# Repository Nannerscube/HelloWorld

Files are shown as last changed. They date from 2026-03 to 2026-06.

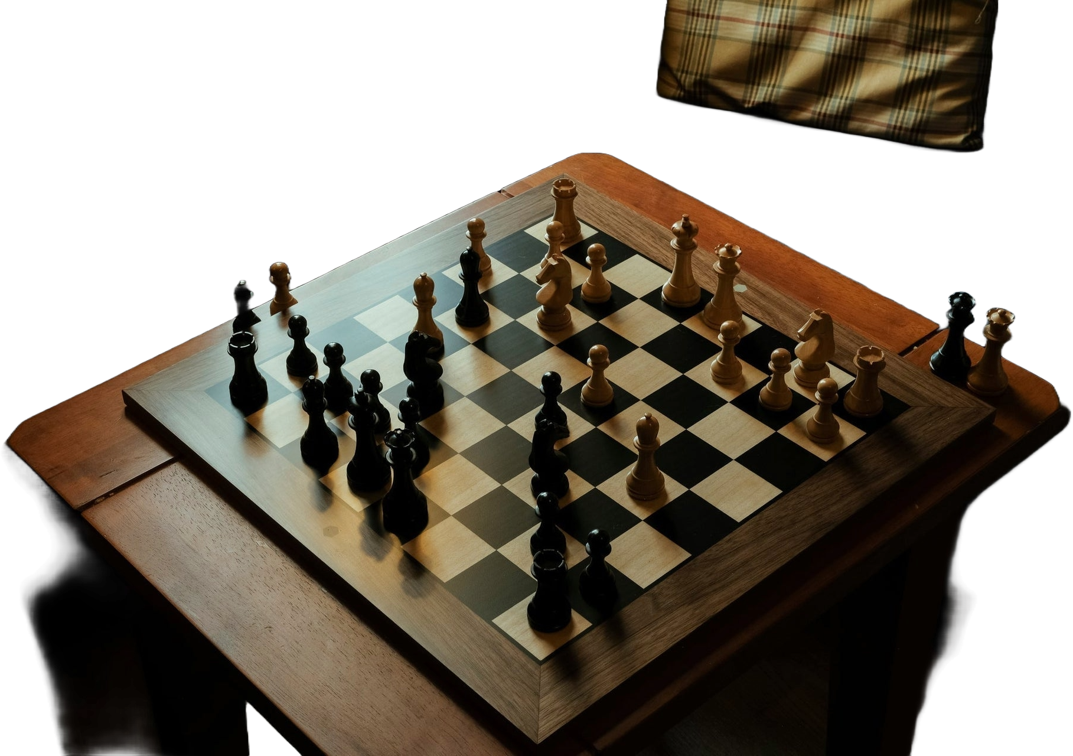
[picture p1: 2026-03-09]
showcase/board_test.jpg

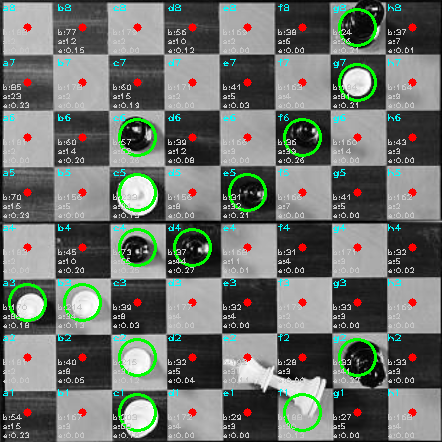
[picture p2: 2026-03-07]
showcase/processed/occupancy_overlay.png

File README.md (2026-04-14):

# Hello World! Chess Bot

A chess-playing robot arm built with Python and C++ (Arduino). It uses computer vision to read the board, Stockfish to calculate the best move, and a 3-axis robot arm to physically execute it — completely autonomously after setup.

## How It Works

The system runs two communication layers:

- **Software layer** — Python handles board state, camera vision (OpenCV), and move generation via Stockfish. Commands like `get_move`, `camera_calibrate`, and `camera_capture_player_move` are exposed to the Arduino via a bridge.
- **Hardware layer** — The Arduino translates logical moves into stepper/servo motor signals, controlling the arm across 3 axes to pick up and place pieces.

**Game loop:**
1. Camera calibrates and captures the initial board state
2. Robot plays as White; player makes a move and presses OK
3. Camera detects the new board state and sends it to Stockfish
4. The arm executes the best move
5. Repeat until checkmate or resignation

## Requirements

### Hardware
| Component | Notes |
|---|---|
| [Arduino UNO Q (2GB/4GB)](https://www.arduino.cc/product-uno-q) | Main controller |
| Arduino CNC Shield + 4× DRV8825 drivers | Motor control |
| 4× NEMA 17 Stepper Motors | Arm movement |
| 1× SG90 Micro Servo | Gripper |
| 3× Endstop Microswitches | Homing |
| Webcam (1080p wide-angle) | Board detection |
| 12V 10A Power Supply | Powers motors |
| 3D-printed arm parts | See [/Arm print](https://github.com/Nannerscube/HelloWorld/tree/main/Arm%20print) |

Total hardware cost: ~€203 + 3D printing

### Software & Libraries

**Arduino:**
- `Arduino_RouterBridge`

**Python (`requirements.txt`):**
```
chess
numpy
opencv-python
```

**External:**
- [Stockfish](https://stockfishchess.org/download/) — place the executable in the AppLabs Python folder, or set the `STOCKFISH_PATH` environment variable

### Optional
- [Visual Studio Code](https://code.visualstudio.com/download)

## Installation

1. Download the ZIP from GitHub and extract the contents onto the Arduino UNO Q
2. Install Python dependencies: `pip install -r requirements.txt`
3. Download Stockfish and place the executable in the AppLabs Python folder

## Configuration

- `ENABLE_PIN = 8`
- Endstops and motor step/dir pins are defined in `sketch.ino`

## Startup Guide

1. Assemble the robot arm — mount motors, gripper, camera, and chessboard in fixed positions
2. Wire Arduino, CNC shield, motors, endstops, button, and servo per the pin mapping; ensure common ground across all components
3. Open AppLabs and create a new project
4. Install the `Arduino_RouterBridge` library and upload `sketch.ino` to the board
5. In the Python environment, ensure `main.py` and `requirements.txt` exist with the required libraries
6. Click **Start** and confirm the bridge reports chess and vision systems are working in the console
7. Power the robot, clear the work area, and press **OK** once — the arm will home itself
8. Press **OK** again to calibrate the camera and verify the board warp
9. Place chess pieces on the board with the robot's side as White
10. Press **OK** again to capture the initial board state — the game begins
11. **Your turn:** make a legal move and press **OK** so the camera captures it
12. **Robot's turn:** wait for the arm to finish and the reference image to refresh before touching the board
13. To stop the game, hold **OK** for ~10 seconds to trigger the resignation flow

## Known Limitations

| Case | Description |
|---|---|
| Uneven lighting | Camera may fail to detect board state correctly |
| Shadows on the board | Can cause false move detections |
| Lighting changes mid-game | Breaks reference frame comparison, causing incorrect detections |
| Castling desync | Engine passes `from_square, to_square` only — rook movement can desync the virtual and physical boards |
| No human promotion support | If the human player reaches promotion, the system has no handler for it |
| No promotion display | Engine promotions are not visually indicated |
| Physical board movement | If the board shifts during play, detection accuracy degrades |

## Project Structure

```
HelloWorld/
├── Arm print/         # 3D print files for the robot arm
├── Python/
│   ├── main.py        # Entry point
│   └── requirements.txt
├── sketch.ino         # Arduino firmware
└── tests/
    ├── grippertest.ino
    └── ...
```

## Acknowledgements

- [Stockfish](https://stockfishchess.org/) — chess engine
- [python-chess](https://python-chess.readthedocs.io/) — board logic
- [OpenCV](https://opencv.org/) — computer vision

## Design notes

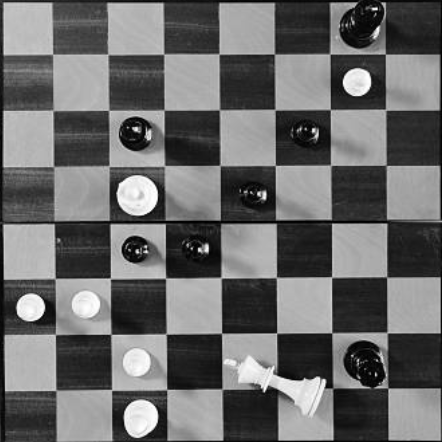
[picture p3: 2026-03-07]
showcase/processed/warped_board.png

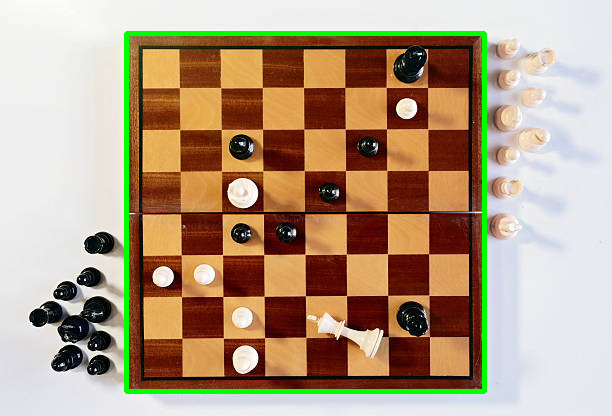
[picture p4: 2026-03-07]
showcase/processed/recognized_board.png

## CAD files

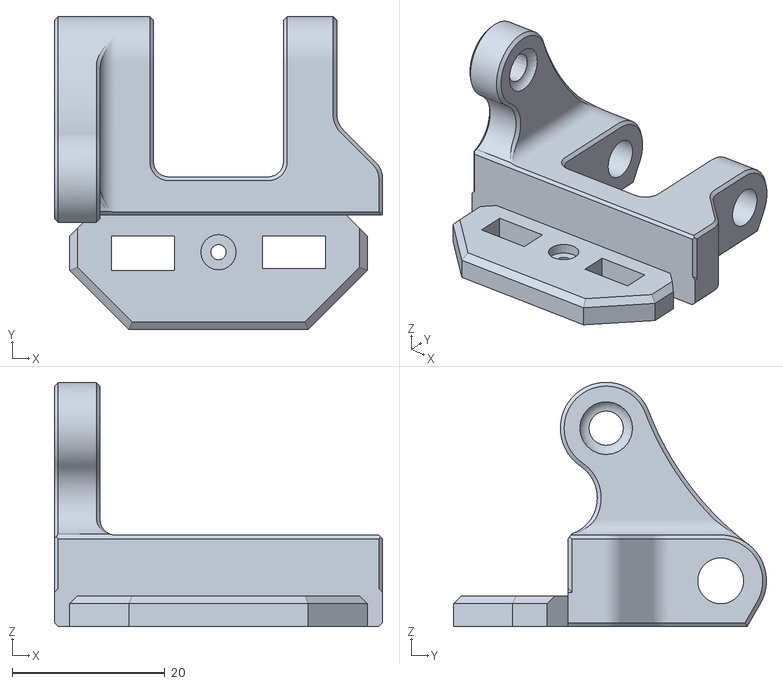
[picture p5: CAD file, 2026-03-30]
Arm print/manipulator.stl
43.0 x 41.0 x 32.0

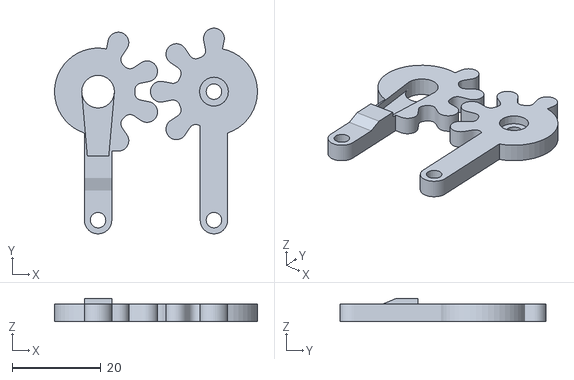
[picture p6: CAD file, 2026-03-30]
Arm print/gears.stl
45.8 x 46.4 x 5.20

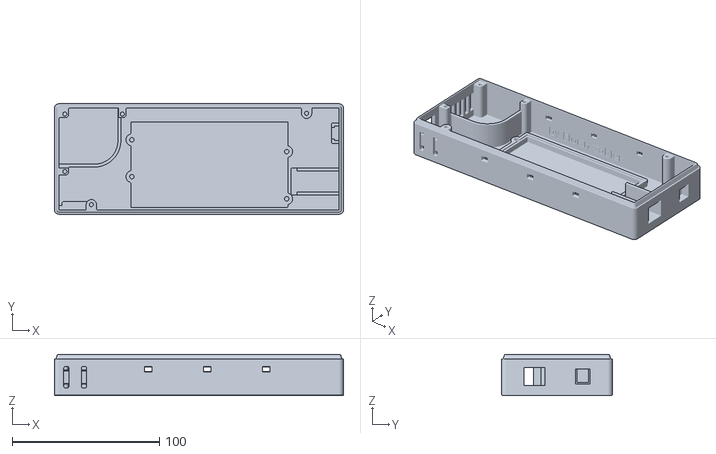
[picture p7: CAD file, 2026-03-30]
Arm print/control_bottom.stl
196.0 x 75.0 x 28.0

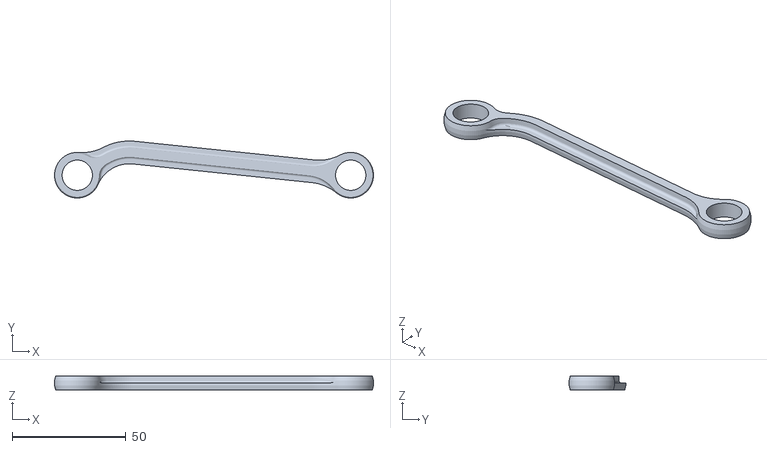
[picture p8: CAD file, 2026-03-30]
Arm print/pleuel_bend.stl
140.0 x 25.0 x 6.00

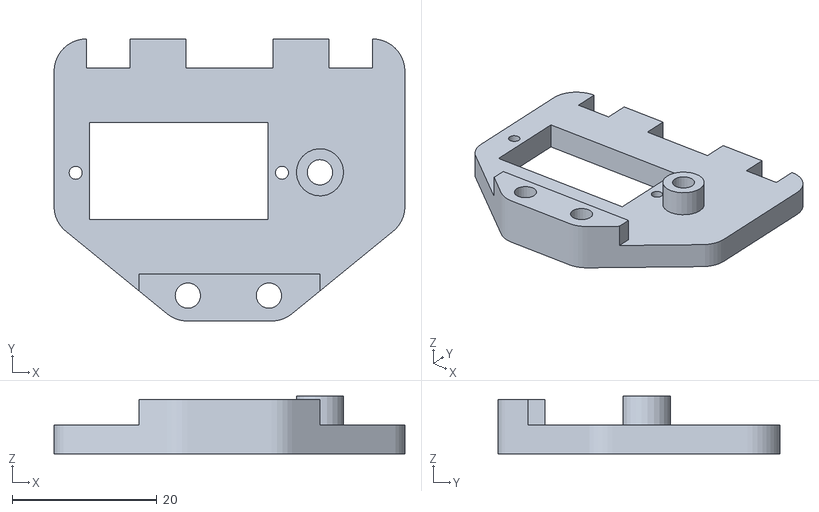
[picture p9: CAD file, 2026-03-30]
Arm print/servo-plate.stl
48.5 x 39.0 x 8.00

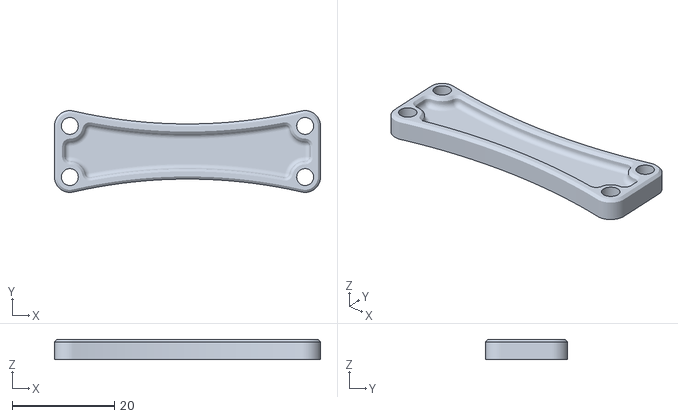
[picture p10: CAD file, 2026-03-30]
Arm print/stabilizer.stl
52.0 x 16.0 x 4.00

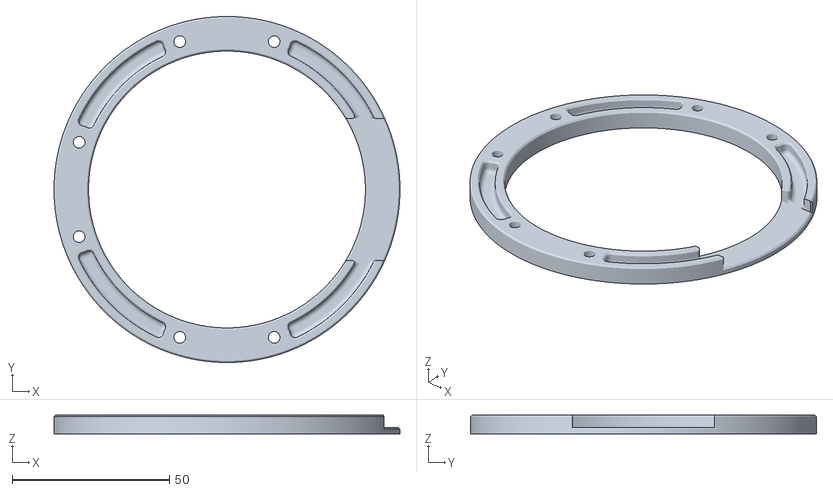
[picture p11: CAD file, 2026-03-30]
Arm print/baseRing.stl
110.0 x 110.0 x 6.00

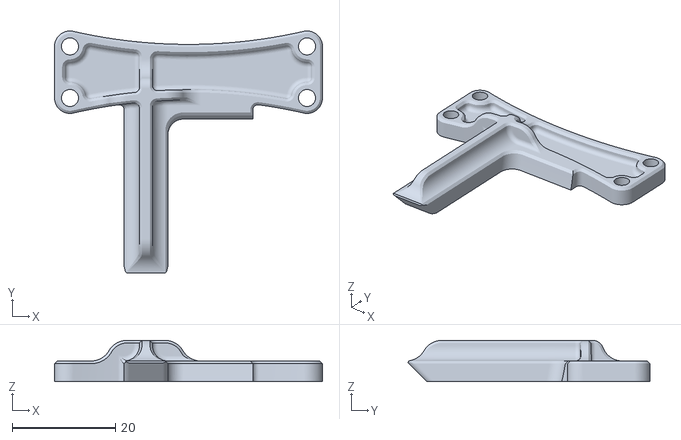
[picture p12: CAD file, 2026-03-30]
Arm print/stabilizer_endstop.stl
52.0 x 47.0 x 8.00

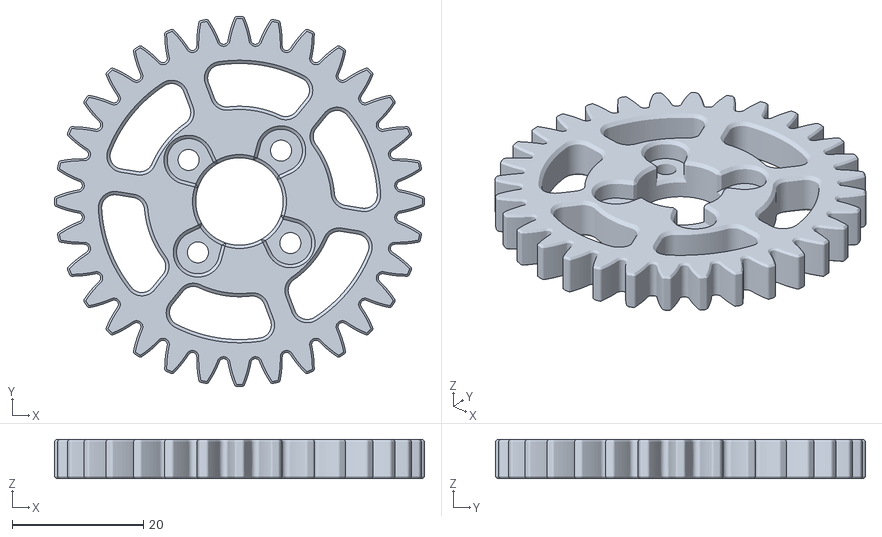
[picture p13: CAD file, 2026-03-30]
Arm print/GearBig_0.05mmTolerance.stl
56.3 x 56.3 x 6.00

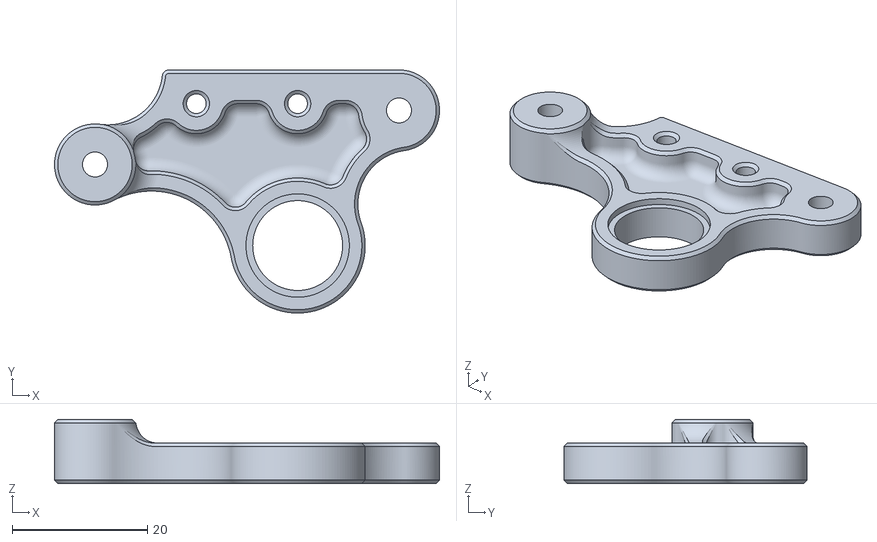
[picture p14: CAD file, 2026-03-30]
Arm print/triplate.stl
57.0 x 36.0 x 9.50

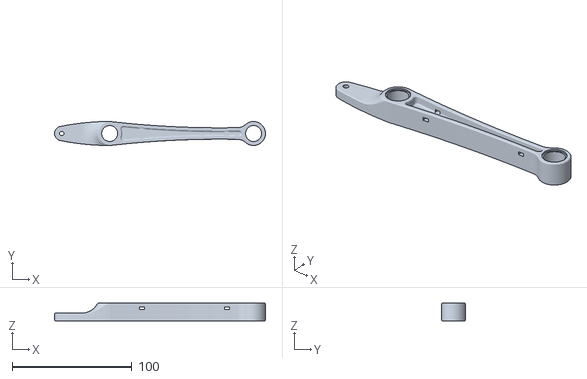
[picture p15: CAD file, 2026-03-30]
Arm print/upperShank.stl
176.0 x 20.0 x 15.0

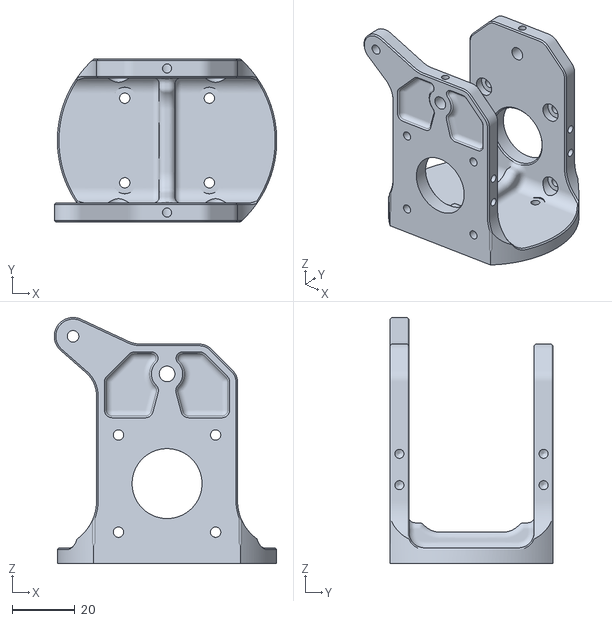
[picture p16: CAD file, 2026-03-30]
Arm print/base.stl
71.0 x 52.0 x 78.5

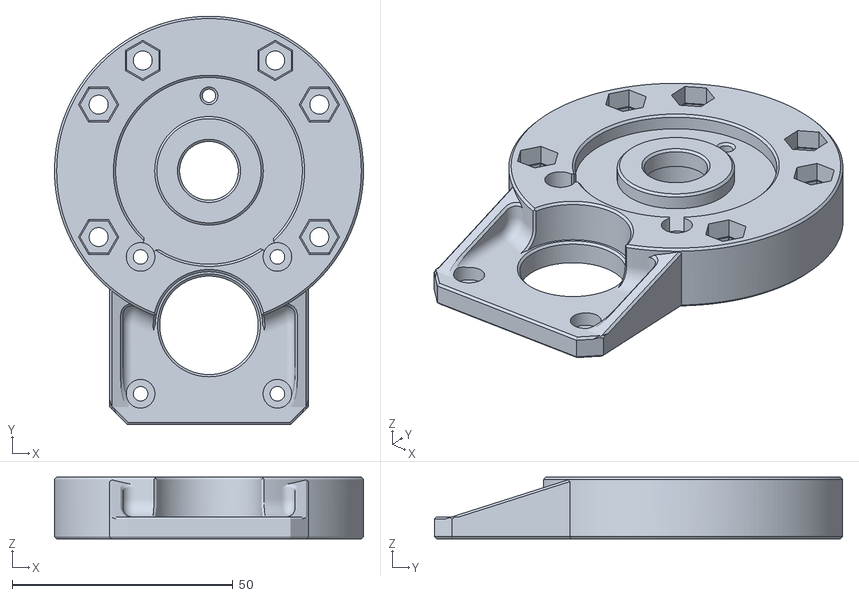
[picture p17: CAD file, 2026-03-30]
Arm print/socket.stl
70.0 x 92.5 x 14.0

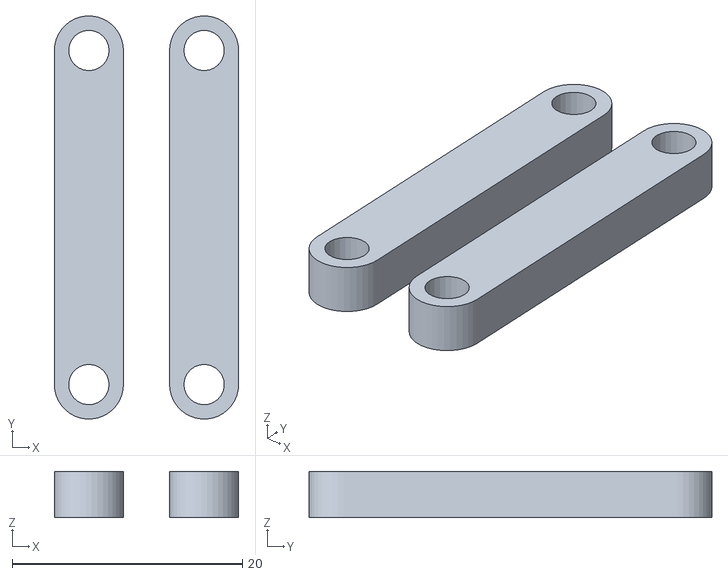
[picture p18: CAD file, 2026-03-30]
Arm print/parallel-bar.stl
16.0 x 35.0 x 4.00

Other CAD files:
Arm print/lever.stl
Arm print/pleuel.stl
Arm print/GearSmall(gold) modified.stl
Arm print/GearSmall.stl
Arm print/GearRotate_0.05mmTolerance.stl
Arm print/grip-part.stl
Arm print/lowerShank.stl

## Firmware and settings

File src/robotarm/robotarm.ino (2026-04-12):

// ██╗  ██╗███████╗██╗     ██╗      ██████╗   ██╗    ██╗ ██████╗ ██████╗ ██╗     ██████╗
// ██║  ██║██╔════╝██║     ██║     ██╔═══██╗  ██║    ██║██╔═══██╗██╔══██╗██║     ██╔══██╗
// ███████║█████╗  ██║     ██║     ██║   ██║  ██║ █╗ ██║██║   ██║██████╔╝██║     ██║  ██║
// ██╔══██║██╔══╝  ██║     ██║     ██║   ██║  ██║███╗██║██║   ██║██╔══██╗██║     ██║  ██║
// ██║  ██║███████╗███████╗███████╗╚██████╔╝  ╚███╔███╔╝╚██████╔╝██║  ██║███████╗██████╔╝
// ╚═╝  ╚═╝╚══════╝╚══════╝╚══════╝ ╚═════╝    ╚══╝╚══╝  ╚═════╝ ╚═╝  ╚═╝╚══════╝╚═════╝

// ██████╗  ██████╗ ██████╗  ██████╗ ████████╗     █████╗ ██████╗ ███╗   ███╗
// ██╔══██╗██╔═══██╗██╔══██╗██╔═══██╗╚══██╔══╝    ██╔══██╗██╔══██╗████╗ ████║
// ██████╔╝██║   ██║██████╔╝██║   ██║   ██║       ███████║██████╔╝██╔████╔██║
// ██╔══██╗██║   ██║██╔══██╗██║   ██║   ██║       ██╔══██║██╔══██╗██║╚██╔╝██║
// ██║  ██║╚██████╔╝██████╔╝╚██████╔╝   ██║       ██║  ██║██║  ██║██║ ╚═╝ ██║
// ╚═╝  ╚═╝ ╚═════╝ ╚═════╝  ╚═════╝    ╚═╝       ╚═╝  ╚═╝╚═╝  ╚═╝╚═╝     ╚═╝
// This file needs to read input from chess notation and make the robot arm make that 

#include <Arduino_RouterBridge.h>


// ██████╗ ██╗███╗   ██╗ ██████╗ ██╗   ██╗████████╗
// ██╔══██╗██║████╗  ██║██╔═══██╗██║   ██║╚══██╔══╝
// ██████╔╝██║██╔██╗ ██║██║   ██║██║   ██║   ██║   
// ██╔═══╝ ██║██║╚██╗██║██║   ██║██║   ██║   ██║   
// ██║     ██║██║ ╚████║╚██████╔╝╚██████╔╝   ██║   
// ╚═╝     ╚═╝╚═╝  ╚═══╝ ╚═════╝  ╚═════╝    ╚═╝   

#define ENABLE_PIN 8

#define X_DIR  5
#define X_STEP 2

#define Y_DIR  6
#define Y_STEP 3

#define Z_DIR  7
#define Z_STEP 4
#define Z_ENDSTOP 11

#define SERVO_PIN 12


//  ██████╗ ██████╗ ███╗   ██╗███████╗████████╗ █████╗ ███╗   ██╗████████╗███████╗
// ██╔════╝██╔═══██╗████╗  ██║██╔════╝╚══██╔══╝██╔══██╗████╗  ██║╚══██╔══╝██╔════╝
// ██║     ██║   ██║██╔██╗ ██║███████╗   ██║   ███████║██╔██╗ ██║   ██║   ███████╗
// ██║     ██║   ██║██║╚██╗██║╚════██║   ██║   ██╔══██║██║╚██╗██║   ██║   ╚════██║
// ╚██████╗╚██████╔╝██║ ╚████║███████║   ██║   ██║  ██║██║ ╚████║   ██║   ███████║
//  ╚═════╝ ╚═════╝ ╚═╝  ╚═══╝╚══════╝   ╚═╝   ╚═╝  ╚═╝╚═╝  ╚═══╝   ╚═╝   ╚══════╝

#define STEPS_PER_REV 50
#define MICROSTEP     1
#define STEP_DELAY_US 6000
#define Y_STEP_DELAY_MS 3000
#define Z_STEP_DELAY_MS 8000  // slower than Y
#define Z_EXTRA_STEPS 100     // extra Z after Y stops

#define X_ROTATE_STEPS 168    // steps for 90 degrees more less

#define GRIPPER_CLOSED 2200
#define GRIPPER_OPEN   1000

#define MAX_MOVES 30

struct Move {
  int  dirPin1, stepPin1;
  bool dir1;
  int  dirPin2, stepPin2;
  bool dir2;
  int  steps;
  bool isTwoMotors;

  Move() {}
  Move(int dp1, int sp1, bool d1, int dp2, int sp2, bool d2, int s, bool two)
    : dirPin1(dp1), stepPin1(sp1), dir1(d1),
      dirPin2(dp2), stepPin2(sp2), dir2(d2),
      steps(s), isTwoMotors(two) {}
};
Move moveQueue[MAX_MOVES];
int  moveCount = 0;

void rememberMove(int dirPin1, int stepPin1, int steps, bool clockwise);
void rememberMove(int dirPin1, int stepPin1, bool dir1,
                  int dirPin2, int stepPin2, bool dir2,
                  int steps);
void goHome();


// ███████╗███████╗████████╗██╗   ██╗██████╗ 
// ██╔════╝██╔════╝╚══██╔══╝██║   ██║██╔══██╗
// ███████╗█████╗     ██║   ██║   ██║██████╔╝
// ╚════██║██╔══╝     ██║   ██║   ██║██╔═══╝ 
// ███████║███████╗   ██║   ╚██████╔╝██║     
// ╚══════╝╚══════╝   ╚═╝    ╚═════╝ ╚═╝     

void setup() {
  Monitor.begin();

  pinMode(X_DIR, OUTPUT);
  pinMode(X_STEP, OUTPUT);
  pinMode(Y_DIR, OUTPUT);
  pinMode(Y_STEP, OUTPUT);
  pinMode(Z_DIR, OUTPUT);
  pinMode(Z_STEP, OUTPUT);
  pinMode(ENABLE_PIN, OUTPUT);
  pinMode(Z_ENDSTOP, INPUT_PULLUP);

  digitalWrite(ENABLE_PIN, LOW);

  // Go to initial position
  delay(2000);
  initializePosition();
  Monitor.println("Finished YZ Home");
  rotateX90(false);
  Monitor.println("Finished X 90 Rotation");
  delay(500);
}


// ██╗      ██████╗  ██████╗ ██████╗ 
// ██║     ██╔═══██╗██╔═══██╗██╔══██╗
// ██║     ██║   ██║██║   ██║██████╔╝
// ██║     ██║   ██║██║   ██║██╔═══╝ 
// ███████╗╚██████╔╝╚██████╔╝██║     
// ╚══════╝ ╚═════╝  ╚═════╝ ╚═╝     

void loop() {
  setGripper(GRIPPER_OPEN);
  goToSquare('h', 8);
  while(true);
}


// ██╗      ██████╗  ██████╗ ██╗ ██████╗
// ██║     ██╔═══██╗██╔════╝ ██║██╔════╝
// ██║     ██║   ██║██║  ███╗██║██║     
// ██║     ██║   ██║██║   ██║██║██║     
// ███████╗╚██████╔╝╚██████╔╝██║╚██████╗
// ╚══════╝ ╚═════╝  ╚═════╝ ╚═╝ ╚═════╝
// Takes a square in chess notation (e.g. "A1", "H8") and moves the arm to it
void goToSquare(char col, int row) {
  moveCount = 0;
  rotateX90(true);
  switch (col) {
    case 'A': case 'a':
      switch (row) {
        case 1: goToA1(); break;
        case 2: goToA2(); break;
        case 3: goToA3(); break;
        case 4: goToA4(); break;
        case 5: goToA5(); break;
        case 6: goToA6(); break;
        case 7: goToA7(); break;
        case 8: goToA8(); break;
      } break;

    case 'B': case 'b':
      switch (row) {
        case 1: goToB1(); break;
        case 2: goToB2(); break;
        case 3: goToB3(); break;
        case 4: goToB4(); break;
        case 5: goToB5(); break;
        case 6: goToB6(); break;
        case 7: goToB7(); break;
        case 8: goToB8(); break;
      } break;

    case 'C': case 'c':
      switch (row) {
        case 1: goToC1(); break;
        case 2: goToC2(); break;
        case 3: goToC3(); break;
        case 4: goToC4(); break;
        case 5: goToC5(); break;
        case 6: goToC6(); break;
        case 7: goToC7(); break;
        case 8: goToC8(); break;
      } break;

    case 'D': case 'd':
      switch (row) {
        case 1: goToD1(); break;
        case 2: goToD2(); break;
        case 3: goToD3(); break;
        case 4: goToD4(); break;
        case 5: goToD5(); break;
        case 6: goToD6(); break;
        case 7: goToD7(); break;
        case 8: goToD8(); break;
      } break;

    case 'E': case 'e':
      switch (row) {
        case 1: goToE1(); break;
        case 2: goToE2(); break;
        case 3: goToE3(); break;
        case 4: goToE4(); break;
        case 5: goToE5(); break;
        case 6: goToE6(); break;
        case 7: goToE7(); break;
        case 8: goToE8(); break;
      } break;

    case 'F': case 'f':
      switch (row) {
        case 1: goToF1(); break;
        case 2: goToF2(); break;
        case 3: goToF3(); break;
        case 4: goToF4(); break;
        case 5: goToF5(); break;
        case 6: goToF6(); break;
        case 7: goToF7(); break;
        case 8: goToF8(); break;
      } break;

    case 'G': case 'g':
      switch (row) {
        case 1: goToG1(); break;
        case 2: goToG2(); break;
        case 3: goToG3(); break;
        case 4: goToG4(); break;
        case 5: goToG5(); break;
        case 6: goToG6(); break;
        case 7: goToG7(); break;
        case 8: goToG8(); break;
      } break;

    case 'H': case 'h':
      switch (row) {
        case 1: goToH1(); break;
        case 2: goToH2(); break;
        case 3: goToH3(); break;
        case 4: goToH4(); break;
        case 5: goToH5(); break;
        case 6: goToH6(); break;
        case 7: goToH7(); break;
        case 8: goToH8(); break;
      } break;
  }
}


// ██████╗ ███████╗ ██████╗ ██████╗ ██████╗ ██████╗ ██╗███╗   ██╗ ██████╗ 
// ██╔══██╗██╔════╝██╔════╝██╔═══██╗██╔══██╗██╔══██╗██║████╗  ██║██╔════╝ 
// ██████╔╝█████╗  ██║     ██║   ██║██████╔╝██║  ██║██║██╔██╗ ██║██║  ███╗
// ██╔══██╗██╔══╝  ██║     ██║   ██║██╔══██╗██║  ██║██║██║╚██╗██║██║   ██║
// ██║  ██║███████╗╚██████╗╚██████╔╝██║  ██║██████╔╝██║██║ ╚████║╚██████╔╝
// ╚═╝  ╚═╝╚══════╝ ╚═════╝ ╚═════╝ ╚═╝  ╚═╝╚═════╝ ╚═╝╚═╝  ╚═══╝ ╚═════╝ 

void rememberMove(int dirPin1, int stepPin1, int steps, bool clockwise) {
  if (moveCount >= MAX_MOVES) return;
  moveQueue[moveCount++] = Move(dirPin1, stepPin1, clockwise, 0, 0, false, steps, false);
}

void rememberMove(int dirPin1, int stepPin1, bool dir1,
                  int dirPin2, int stepPin2, bool dir2,
                  int steps) {
  if (moveCount >= MAX_MOVES) return;
  moveQueue[moveCount++] = Move(dirPin1, stepPin1, dir1, dirPin2, stepPin2, dir2, steps, true);
}

void goHome() {
  for (int i = moveCount - 1; i >= 0; i--) {
    Move& m = moveQueue[i];
    if (m.isTwoMotors) {
      stepTwoMotors(m.dirPin1, m.stepPin1, !m.dir1,
                    m.dirPin2, m.stepPin2, !m.dir2,
                    m.steps);
    } else {
      stepMotor(m.dirPin1, m.stepPin1, m.steps, !m.dir1);
    }
  }
  moveCount = 0;
  rotateX90(false);
  delay(300);
}


// ███╗   ███╗ ██████╗ ████████╗ ██████╗ ██████╗ ███████╗
// ████╗ ████║██╔═══██╗╚══██╔══╝██╔═══██╗██╔══██╗██╔════╝
// ██╔████╔██║██║   ██║   ██║   ██║   ██║██████╔╝███████╗
// ██║╚██╔╝██║██║   ██║   ██║   ██║   ██║██╔══██╗╚════██║
// ██║ ╚═╝ ██║╚██████╔╝   ██║   ╚██████╔╝██║  ██║███████║
// ╚═╝     ╚═╝ ╚═════╝    ╚═╝    ╚═════╝ ╚═╝  ╚═╝╚══════╝

void setGripper(unsigned int pulse) {
  for (unsigned char i = 0; i < 8; i++) {
    digitalWrite(SERVO_PIN, HIGH);
    delayMicroseconds(pulse);
    digitalWrite(SERVO_PIN, LOW);
  }
}

void stepMotor(int dirPin, int stepPin, int steps, bool clockwise) {
  digitalWrite(dirPin, clockwise ? HIGH : LOW);
  delay(1);
  for (int i = 0; i < steps * MICROSTEP; i++) {
    digitalWrite(stepPin, HIGH);
    delayMicroseconds(STEP_DELAY_US);
    digitalWrite(stepPin, LOW);
    delayMicroseconds(STEP_DELAY_US);
  }
}

void stepTwoMotors(int dirPin1, int stepPin1, bool dir1,
                   int dirPin2, int stepPin2, bool dir2,
                   int steps) {
  digitalWrite(dirPin1, dir1 ? HIGH : LOW);
  digitalWrite(dirPin2, dir2 ? HIGH : LOW);
  delay(1);
  for (int i = 0; i < steps * MICROSTEP; i++) {
    digitalWrite(stepPin1, HIGH);
    digitalWrite(stepPin2, HIGH);
    delayMicroseconds(STEP_DELAY_US);
    digitalWrite(stepPin1, LOW);
    digitalWrite(stepPin2, LOW);
    delayMicroseconds(STEP_DELAY_US);
  }
}


// ██████╗  ██████╗ ███████╗██╗████████╗██╗ ██████╗ ███╗   ██╗███████╗
// ██╔══██╗██╔═══██╗██╔════╝██║╚══██╔══╝██║██╔═══██╗████╗  ██║██╔════╝
// ██████╔╝██║   ██║███████╗██║   ██║   ██║██║   ██║██╔██╗ ██║███████╗
// ██╔═══╝ ██║   ██║╚════██║██║   ██║   ██║██║   ██║██║╚██╗██║╚════██║
// ██║     ╚██████╔╝███████║██║   ██║   ██║╚██████╔╝██║ ╚████║███████║
// ╚═╝      ╚═════╝ ╚══════╝╚═╝   ╚═╝   ╚═╝ ╚═════╝ ╚═╝  ╚═══╝╚══════╝

void initializePosition() {
  digitalWrite(Y_DIR, LOW);  // Y backward
  digitalWrite(Z_DIR, HIGH); // Z up

  int zCounter = 0;

  while (digitalRead(Z_ENDSTOP) == LOW) {
    digitalWrite(Y_STEP, HIGH);
    delayMicroseconds(Y_STEP_DELAY_MS);
    digitalWrite(Y_STEP, LOW);
    delayMicroseconds(Y_STEP_DELAY_MS);

    zCounter++;
    if (zCounter >= 3) {
      digitalWrite(Z_STEP, HIGH);
      delayMicroseconds(Z_STEP_DELAY_MS);
      digitalWrite(Z_STEP, LOW);
      delayMicroseconds(Z_STEP_DELAY_MS);
      zCounter = 0;
    }
  }

  // Small back off on Y
  digitalWrite(Y_DIR, HIGH);
  for (int i = 0; i < 20; i++) {
    digitalWrite(Y_STEP, HIGH);
    delayMicroseconds(Y_STEP_DELAY_MS);
    digitalWrite(Y_STEP, LOW);
    delayMicroseconds(Y_STEP_DELAY_MS);
  }

  // Moving Z further up
  for (int i = 0; i < Z_EXTRA_STEPS; i++) {
    digitalWrite(Z_STEP, HIGH);
    delayMicroseconds(Z_STEP_DELAY_MS);
    digitalWrite(Z_STEP, LOW);
    delayMicroseconds(Z_STEP_DELAY_MS);
  }
}

void rotateX90(bool clockwise) {
  digitalWrite(X_DIR, clockwise ? HIGH : LOW);
  delay(1);
  for (int i = 0; i < X_ROTATE_STEPS; i++) {
    digitalWrite(X_STEP, HIGH);
    delayMicroseconds(10000);
    digitalWrite(X_STEP, LOW);
    delayMicroseconds(10000);
  }
}


void goToA1() {
  rememberMove(Y_DIR, Y_STEP, STEPS_PER_REV, false);
  stepMotor(Y_DIR, Y_STEP, STEPS_PER_REV, false);
  delay(500);
  rememberMove(Z_DIR, Z_STEP, STEPS_PER_REV, false);
  stepMotor(Z_DIR, Z_STEP, STEPS_PER_REV, false);
  delay(500);
  rememberMove(X_DIR, X_STEP, 120, true);
  stepMotor(X_DIR, X_STEP, 120, true);
  delay(500);
  rememberMove(Z_DIR, Z_STEP, 20, true);
  stepMotor(Z_DIR, Z_STEP, 20, true);
  delay(500);
  rememberMove(Z_DIR, Z_STEP, false,
                Y_DIR, Y_STEP, true,
                90);
  stepTwoMotors(Z_DIR, Z_STEP, false,
                Y_DIR, Y_STEP, true,
                90);
  delay(500);
  rememberMove(Z_DIR, Z_STEP, 8, false);
  stepMotor(Z_DIR, Z_STEP, 8, false);
  delay(500);
  rememberMove(Z_DIR, Z_STEP, false,
                Y_DIR, Y_STEP, true,
                30);
  stepTwoMotors(Z_DIR, Z_STEP, false,
                Y_DIR, Y_STEP, true,
                30);
  delay(500);
  setGripper(GRIPPER_CLOSED);
  goHome();
}
void goToA2() {
  rememberMove(Y_DIR, Y_STEP, STEPS_PER_REV, false);
  stepMotor(Y_DIR, Y_STEP, STEPS_PER_REV, false);
  delay(500);
  rememberMove(Z_DIR, Z_STEP, STEPS_PER_REV, false);
  stepMotor(Z_DIR, Z_STEP, STEPS_PER_REV, false);
  delay(500);
  rememberMove(X_DIR, X_STEP, 104  , true);
  stepMotor(X_DIR, X_STEP, 104, true);
  delay(500);
  rememberMove(Z_DIR, Z_STEP, 35, true);
  stepMotor(Z_DIR, Z_STEP, 35, true);
  delay(500);
  rememberMove(Z_DIR, Z_STEP, false,
                Y_DIR, Y_STEP, true,
                107);
  stepTwoMotors(Z_DIR, Z_STEP, false,
                Y_DIR, Y_STEP, true,
                107);
  delay(500);
  rememberMove(Z_DIR, Z_STEP, 8, false);
  stepMotor(Z_DIR, Z_STEP, 8, false);
  delay(500);
  rememberMove(Z_DIR, Z_STEP, false,
                Y_DIR, Y_STEP, true,
                10);
  stepTwoMotors(Z_DIR, Z_STEP, false,
                Y_DIR, Y_STEP, true,
                10);
  delay(500);
  setGripper(GRIPPER_CLOSED);
  goHome();
}
void goToA3() {
  rememberMove(Y_DIR, Y_STEP, STEPS_PER_REV, false);
  stepMotor(Y_DIR, Y_STEP, STEPS_PER_REV, false);
  delay(500);
  rememberMove(Z_DIR, Z_STEP, STEPS_PER_REV, false);
  stepMotor(Z_DIR, Z_STEP, STEPS_PER_REV, false);
  delay(500);
  rememberMove(X_DIR, X_STEP, 91, true);
  stepMotor(X_DIR, X_STEP, 91, true);
  delay(500);
  rememberMove(Z_DIR, Z_STEP, 55, true);
  stepMotor(Z_DIR, Z_STEP, 55, true);
  delay(500);
  rememberMove(Z_DIR, Z_STEP, false,
                Y_DIR, Y_STEP, true,
                107);
  stepTwoMotors(Z_DIR, Z_STEP, false,
                Y_DIR, Y_STEP, true,
                107);
  delay(500);
  rememberMove(Z_DIR, Z_STEP, 8, false);
  stepMotor(Z_DIR, Z_STEP, 8, false);
  delay(500);
  rememberMove(Z_DIR, Z_STEP, false,
                Y_DIR, Y_STEP, true,
                20);
  stepTwoMotors(Z_DIR, Z_STEP, false,
                Y_DIR, Y_STEP, true,
                20);
  delay(500);
  setGripper(GRIPPER_CLOSED);
  goHome();
}
void goToA4() {
  rememberMove(Y_DIR, Y_STEP, STEPS_PER_REV, false);
  stepMotor(Y_DIR, Y_STEP, STEPS_PER_REV, false);
  delay(500);
  rememberMove(Z_DIR, Z_STEP, STEPS_PER_REV, false);
  stepMotor(Z_DIR, Z_STEP, STEPS_PER_REV, false);
  delay(500);
  rememberMove(X_DIR, X_STEP, 79, true);
  stepMotor(X_DIR, X_STEP, 79, true);
  delay(500);
  rememberMove(Z_DIR, Z_STEP, 75, true);
  stepMotor(Z_DIR, Z_STEP, 75, true);
  delay(500);
  rememberMove(Z_DIR, Z_STEP, false,
                Y_DIR, Y_STEP, true,
                115);
  stepTwoMotors(Z_DIR, Z_STEP, false,
                Y_DIR, Y_STEP, true,
                115);
  delay(500);
  rememberMove(Z_DIR, Z_STEP, 10, false);
  stepMotor(Z_DIR, Z_STEP, 10, false);
  delay(500);
  rememberMove(Z_DIR, Z_STEP, false,
                Y_DIR, Y_STEP, true,
                30);
  stepTwoMotors(Z_DIR, Z_STEP, false,
                Y_DIR, Y_STEP, true,
                30);
  delay(500);
  setGripper(GRIPPER_CLOSED);
  goHome();
}
void goToA5() {
  rememberMove(Y_DIR, Y_STEP, STEPS_PER_REV, false);
  stepMotor(Y_DIR, Y_STEP, STEPS_PER_REV, false);
  delay(500);
  rememberMove(Z_DIR, Z_STEP, STEPS_PER_REV, false);
  stepMotor(Z_DIR, Z_STEP, STEPS_PER_REV, false);
  delay(500);
  rememberMove(X_DIR, X_STEP, 71, true);
  stepMotor(X_DIR, X_STEP, 71, true);
  delay(500);
  rememberMove(Z_DIR, Z_STEP, 70, true);
  stepMotor(Z_DIR, Z_STEP, 70, true);
  delay(500);
  rememberMove(Z_DIR, Z_STEP, false,
                Y_DIR, Y_STEP, true,
                125);
  stepTwoMotors(Z_DIR, Z_STEP, false,
                Y_DIR, Y_STEP, true,
                125);
  delay(500);
  rememberMove(Z_DIR, Z_STEP, 40, true);
  stepMotor(Z_DIR, Z_STEP, 40, true);
  delay(500);
  rememberMove(Z_DIR, Z_STEP, 8, false);
  stepMotor(Z_DIR, Z_STEP, 8, false);
  delay(500);
  rememberMove(Z_DIR, Z_STEP, false,
                Y_DIR, Y_STEP, true,
                30);
  stepTwoMotors(Z_DIR, Z_STEP, false,
                Y_DIR, Y_STEP, true,
                30);
  delay(500);
  setGripper(GRIPPER_CLOSED);
  goHome();
}
void goToA6() {
    rememberMove(Y_DIR, Y_STEP, STEPS_PER_REV, false);
  stepMotor(Y_DIR, Y_STEP, STEPS_PER_REV, false);
  delay(500);
  rememberMove(Z_DIR, Z_STEP, STEPS_PER_REV, false);
  stepMotor(Z_DIR, Z_STEP, STEPS_PER_REV, false);
  delay(500);
  rememberMove(X_DIR, X_STEP, 70, true);
  stepMotor(X_DIR, X_STEP, 70, true);
  delay(500);
  rememberMove(Z_DIR, Z_STEP, 70, true);
  stepMotor(Z_DIR, Z_STEP, 70, true);
  delay(500);
  rememberMove(Z_DIR, Z_STEP, false,
                Y_DIR, Y_STEP, true,
                125);
  stepTwoMotors(Z_DIR, Z_STEP, false,
                Y_DIR, Y_STEP, true,
                125);
  delay(500);
  rememberMove(Z_DIR, Z_STEP, 60, true);
  stepMotor(Z_DIR, Z_STEP, 60, true);
  delay(500);
  rememberMove(Z_DIR, Z_STEP, false,
                Y_DIR, Y_STEP, true,
                40);
  stepTwoMotors(Z_DIR, Z_STEP, false,
                Y_DIR, Y_STEP, true,
                40);
  delay(500);
  setGripper(GRIPPER_CLOSED);
  goHome();
}
void goToA7() {
  rememberMove(Y_DIR, Y_STEP, STEPS_PER_REV, false);
  stepMotor(Y_DIR, Y_STEP, STEPS_PER_REV, false);
  delay(500);
  rememberMove(Z_DIR, Z_STEP, STEPS_PER_REV, false);
  stepMotor(Z_DIR, Z_STEP, STEPS_PER_REV, false);
  delay(500);
  rememberMove(X_DIR, X_STEP, 65, true);
  stepMotor(X_DIR, X_STEP, 65, true);
  delay(500);
  rememberMove(Z_DIR, Z_STEP, 70, true);
  stepMotor(Z_DIR, Z_STEP, 70, true);
  delay(500);
  rememberMove(Z_DIR, Z_STEP, false,
                Y_DIR, Y_STEP, true,
                125);
  stepTwoMotors(Z_DIR, Z_STEP, false,
                Y_DIR, Y_STEP, true,
                125);
  delay(500);
  rememberMove(Z_DIR, Z_STEP, 95, true);
  stepMotor(Z_DIR, Z_STEP, 95, true);
  delay(500);
  rememberMove(Z_DIR, Z_STEP, false,
                Y_DIR, Y_STEP, true,
                55);
  stepTwoMotors(Z_DIR, Z_STEP, false,
                Y_DIR, Y_STEP, true,
                55);
  delay(500);
  setGripper(GRIPPER_CLOSED);
  goHome();
}
void goToA8() {
  rememberMove(Y_DIR, Y_STEP, STEPS_PER_REV, false);
  stepMotor(Y_DIR, Y_STEP, STEPS_PER_REV, false);
  delay(500);
  rememberMove(Z_DIR, Z_STEP, STEPS_PER_REV, false);
  stepMotor(Z_DIR, Z_STEP, STEPS_PER_REV, false);
  delay(500);
  rememberMove(X_DIR, X_STEP, 58, true);
  stepMotor(X_DIR, X_STEP, 58, true);
  delay(500);
  rememberMove(Z_DIR, Z_STEP, 70, true);
  stepMotor(Z_DIR, Z_STEP, 70, true);
  delay(500);
  rememberMove(Z_DIR, Z_STEP, false,
                Y_DIR, Y_STEP, true,
                125);
  stepTwoMotors(Z_DIR, Z_STEP, false,
                Y_DIR, Y_STEP, true,
                125);
  delay(500);
  rememberMove(Z_DIR, Z_STEP, 70, true);
  stepMotor(Z_DIR, Z_STEP, 70, true);
  delay(500);
  rememberMove(Z_DIR, Z_STEP, false,
                Y_DIR, Y_STEP, true,
                33);
  stepTwoMotors(Z_DIR, Z_STEP, false,
                Y_DIR, Y_STEP, true,
                33);
  delay(500);
  rememberMove(Z_DIR, Z_STEP, 70, true);
  stepMotor(Z_DIR, Z_STEP, 70, true);
  delay(500);
  rememberMove(Z_DIR, Z_STEP, false,
                Y_DIR, Y_STEP, true,
                60);
  stepTwoMotors(Z_DIR, Z_STEP, false,
                Y_DIR, Y_STEP, true,
                60);
  delay(500);
  setGripper(GRIPPER_CLOSED);
  goHome();
}

void goToB1() {
  rememberMove(Y_DIR, Y_STEP, STEPS_PER_REV, false);
  stepMotor(Y_DIR, Y_STEP, STEPS_PER_REV, false);
  delay(500);
  rememberMove(Z_DIR, Z_STEP, STEPS_PER_REV, false);
  stepMotor(Z_DIR, Z_STEP, STEPS_PER_REV, false);
  delay(500);
  rememberMove(X_DIR, X_STEP, 94, true);
  stepMotor(X_DIR, X_STEP, 94, true);
  delay(500);
  rememberMove(Z_DIR, Z_STEP, 30, true);
  stepMotor(Z_DIR, Z_STEP, 30, true);
  delay(500);
  rememberMove(Z_DIR, Z_STEP, false,
                Y_DIR, Y_STEP, true,
                70);
  stepTwoMotors(Z_DIR, Z_STEP, false,
                Y_DIR, Y_STEP, true,
                70);
  delay(500);
  rememberMove(Z_DIR, Z_STEP, 40, false);
  stepMotor(Z_DIR, Z_STEP, 40, false);
  delay(500);
  rememberMove(Z_DIR, Z_STEP, false,
                Y_DIR, Y_STEP, true,
                50);
  stepTwoMotors(Z_DIR, Z_STEP, false,
                Y_DIR, Y_STEP, true,
                50);
  delay(500);
  setGripper(GRIPPER_CLOSED);
  goHome();
}
void goToB2() {
  rememberMove(Y_DIR, Y_STEP, STEPS_PER_REV, false);
  stepMotor(Y_DIR, Y_STEP, STEPS_PER_REV, false);
  delay(500);
  rememberMove(Z_DIR, Z_STEP, STEPS_PER_REV, false);
  stepMotor(Z_DIR, Z_STEP, STEPS_PER_REV, false);
  delay(500);
  rememberMove(X_DIR, X_STEP, 80, true);
  stepMotor(X_DIR, X_STEP, 80, true);
  delay(500);
  rememberMove(Z_DIR, Z_STEP, 30, true);
  stepMotor(Z_DIR, Z_STEP, 30, true);
  delay(500);
  rememberMove(Z_DIR, Z_STEP, false,
                Y_DIR, Y_STEP, true,
                70);
  stepTwoMotors(Z_DIR, Z_STEP, false,
                Y_DIR, Y_STEP, true,
                70);
  delay(500);
  rememberMove(Z_DIR, Z_STEP, 8, false);
  stepMotor(Z_DIR, Z_STEP, 8, false);
  delay(500);
  rememberMove(Z_DIR, Z_STEP, false,
                Y_DIR, Y_STEP, true,
                45);
  stepTwoMotors(Z_DIR, Z_STEP, false,
                Y_DIR, Y_STEP, true,
                45);
  delay(500);
  setGripper(GRIPPER_CLOSED);
  goHome();
}
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

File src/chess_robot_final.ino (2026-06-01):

#include <Arduino_RouterBridge.h>
BridgeClass Bridge(Serial1);

#define X_STEP 2
#define X_DIR 5
#define Y_STEP 3
#define Y_DIR 6
#define Z_STEP 4
#define Z_DIR 7
#define ENABLE 8
#define BUTTON_OK A0
#define Z_ENDSTOP 11
#define GRIPPER_PIN 12

#define STEPS_PER_REV 50
#define MICROSTEP 1
#define STEP_DELAY_US 6000
#define Y_STEP_DELAY_MS 3000
#define Z_STEP_DELAY_MS 8000
#define Z_EXTRA_STEPS 100
#define X_ROTATE_STEPS 168
#define GRIPPER_CLOSED 2800
#define GRIPPER_OPEN 1000
#define MAX_MOVES 30

const unsigned long DEBOUNCE_DELAY = 50;
const unsigned long LONG_PRESS_TIME = 3000;
const unsigned long STATUS_MESSAGE_MS = 3000;

bool robotTurn = false;
bool gameActive = false;
bool setupComplete = false;
String robotNextMove = "----";
String statusMessage = "";
unsigned long statusMessageUntil = 0;

bool buttonOkState = false;
bool buttonOkLastState = false;
bool buttonOkPressedLatch = false;
bool buttonOkReleaseRequired = false;
unsigned long buttonOkDebounceTime = 0;
unsigned long buttonOkPressStart = 0;

bool calibrationDone = false;
bool verifyDone = false;
bool initialCaptureDone = false;

unsigned int gripperTargetPulse = 2200;

// Square sequence part
#define MAX_SEQ_STEPS 10

struct SquareStep {
  int  dirPin1, stepPin1;
  bool dir1;
  int  dirPin2, stepPin2; // 0,0 = single motor
  bool dir2;
  int  steps;
};

#define END { 0,0,false,0,0,false,0 }
////////////////////

void setStatusMessage(const String& message) {
  statusMessage = message;
  statusMessageUntil = millis() + STATUS_MESSAGE_MS;
  Serial.println(message);
}

String shortenMessage(String message) {
  message.replace("success:", "");
  message.replace("fail:", "");
  message.replace("unstable:", "");
  if (message.length() > 60) return message.substring(0, 60);
  return message;
}

bool callBridgeStep(const char* command, String& data) {
  data = "";
  Serial.print("[DEBUG] Bridge call -> ");
  Serial.println(command);
  bool ok = Bridge.call(command).result(data);
  Serial.print("[DEBUG] Bridge response <- ");
  Serial.println(data);
  if (!ok) {
    data = "fail:Bridge call failed";
    Serial.println("[DEBUG] Bridge call transport failed");
    return false;
  }
  return data.startsWith("success:");
}

void readButtons() {
  unsigned long currentTime = millis();
  bool okReading = (digitalRead(BUTTON_OK) == LOW);
  if (okReading != buttonOkLastState) {
    buttonOkDebounceTime = currentTime;
    if (okReading) buttonOkPressStart = currentTime;
  }
  if ((currentTime - buttonOkDebounceTime) > DEBOUNCE_DELAY && okReading != buttonOkState) {
    buttonOkState = okReading;
  }
  buttonOkLastState = okReading;
}

bool buttonOkPressed() {
  if (buttonOkReleaseRequired) {
    if (!buttonOkState) {
      buttonOkReleaseRequired = false;
      buttonOkPressedLatch = false;
    }
    return false;
  }

  if (buttonOkState && !buttonOkPressedLatch) {
    buttonOkPressedLatch = true;
    return true;
  }
  if (!buttonOkState) buttonOkPressedLatch = false;
  return false;
}

bool buttonOkLongPress() {
  if (!buttonOkReleaseRequired && buttonOkState && (millis() - buttonOkPressStart >= LONG_PRESS_TIME)) {
    buttonOkPressStart = millis() + 10000;
    return true;
  }
  return false;
}

void requireButtonRelease() {
  buttonOkReleaseRequired = true;
  buttonOkPressedLatch = true;
  buttonOkPressStart = millis();
}

void toggleTurn() {
  if (robotTurn) {
    robotTurn = false;
  } else {
    robotTurn = true;
  }
}

void logUiState() {
  if (statusMessage.length() > 0 && millis() < statusMessageUntil) {
    Serial.print("[STATUS] ");
    Serial.println(statusMessage);
  }
  if (gameActive) {
    Serial.print("[TURN] ");
    Serial.println(robotTurn ? "Robot" : "Player");
    Serial.print("[NEXT MOVE] ");
    Serial.println(robotNextMove);
  }
}

bool goToPiecePlace() {
  return true;
}

bool parseSquare(const char* square, char& fileOut, int& rankOut) {
  if (square == nullptr || strlen(square) < 2) return false;
  char file = square[0];
  if (file >= 'a' && file <= 'h') file -= 32;
  int rank = square[1] - '0';
  if (file < 'A' || file > 'H' || rank < 1 || rank > 8) return false;
  fileOut = file;
  rankOut = rank;
  return true;
}

void retractArmToHome() {
  initializePosition();
  rotateX90(false);
  setGripper(GRIPPER_CLOSED);
}

void performSquareAction(char file, int rank, unsigned int targetPulse) {
  gripperTargetPulse = targetPulse;
  goToSquare(file, rank);
}

bool pickupFromSquare(const char* square) {
  char file;
  int rank;
  if (!parseSquare(square, file, rank)) return false;
  setGripper(GRIPPER_OPEN);
  delay(500);
  performSquareAction(file, rank, GRIPPER_CLOSED);
  return true;
}

bool placeToSquare(const char* square) {
  char file;
  int rank;
  if (!parseSquare(square, file, rank)) return false;
  performSquareAction(file, rank, GRIPPER_OPEN);
  return true;
}

bool removeCapturedPiece(const char* square) {
  if (!pickupFromSquare(square)) return false;
  if (!goToPiecePlace()) return false;
  setGripper(GRIPPER_OPEN);
  delay(500);
  return true;
}

void executeUCIMove(const char* sq1, const char* sq2, int p1, int p2) {
  if (p2 != 0) {
    if (!removeCapturedPiece(sq2)) {
      setStatusMessage("Failed to remove captured piece");
      return;
    }
  }

  if (!pickupFromSquare(sq1)) {
    setStatusMessage("Failed to pick up source piece");
    return;
  }

  if (!placeToSquare(sq2)) {
    setStatusMessage("Failed to place piece on destination");
    return;
  }

  setGripper(GRIPPER_CLOSED);
  delay(500);
}

void startGame() {
  Bridge.call("reset_game");
  gameActive = true;
  setupComplete = true;
  robotTurn = true;
  robotNextMove = "----";
  statusMessage = "";
  requireButtonRelease();
  Bridge.call("log_event", "Game started. Robot is White.");
  Serial.println("[GAME] Started");
}

void endGame() {
  gameActive = false;
  Bridge.call("log_event", "Game resigned.");
  Serial.println("[GAME] Ended");
}
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

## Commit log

2026-02-06 Added robot arm ino file, initialized some code i'm pretty certain we're going to use
2026-03-03 Initial testing of camera and board state recognition
2026-03-04 identification script used for servos of sample arm
2026-03-27 added file for testing motors
2026-03-27 added test file for going to all the coordinates on the chessboard, still needs calibration
2026-03-30 Added all stl files
    [GearBig_0.05mmTolerance.stl, GearRotate_0.05mmTolerance.stl, GearSmall(gold) modified.stl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]
2026-03-30 added moving sequence for arm
2026-03-30 Vision added and main logic added. These are the codes for Lennon's group but as we colleborated and I worked on a lot of their code it will only be reworked to fit our robot
    [sketch.ino]
2026-04-01 added a test for the gripper
2026-04-01 debugging added to reference frame refreshing, added scoring and higher penalty for capturing, added initial rotation fix, added stockfish path finding, added adaptive square thresholds
2026-04-02 Added test code for the endstop Added starting and home position test code
2026-04-03 remade robot arm code, all thats left to do it hardcode positions in
2026-04-10 updated tests, current working code
2026-04-12 Remove AccelStepper from Arduino libraries list
    Removed 'AccelStepper' from the list of Arduino libraries.
2026-06-01 - Moved legacy version of the arm code to a separete folder. - sketch.ino code was optimized and cleaned by: - Reduced the amount of lines from 3042 -> 661 lines by replacing all the goToXX() functio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
